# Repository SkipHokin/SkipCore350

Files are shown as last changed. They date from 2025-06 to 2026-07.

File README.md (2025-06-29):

# SkipCore350 Project Context & Vision

**Project Name**: SkipCore350  
**Type**: Open Source CoreXY 3D Printer  
**Build Volume**: 350mm x 350mm x 350mm  
**Lead**: Skip Hokin (aka "Skip")

---

## ✨ Vision Statement

To design and build a high-performance, low-cost, fully enclosed CoreXY 3D printer using open-source principles, V-slot extrusions, and widely available components. SkipCore350 aims to be:

- Builder-friendly and easily replicable
- Mechanically robust with smooth motion (MGN12 rails + GT2 9mm belts)
- Modular and maintainable
- Capable of printing engineering-grade filaments
- Designed for clean enclosure and cable management

The goal is to offer makers a DIY alternative to high-end machines, blending the precision of industrial designs with the accessibility of community-driven innovation.

---

## 📊 Project Overview

SkipCore350 is a fusion of SimpleCore-style motion with modern practices:

- CoreXY motion system for speed and accuracy
- Triple Z leadscrew driven by a single stepper via GT2 belt
- Full 2020/2040 V-slot aluminum frame
- MGN12H rails on all axes for rigidity and future upgradeability
- Compatibility with BTT Pad7 and SKR-based boards
- Designed around off-the-shelf parts and printable brackets

Future-proofed to support direct-drive or Bowden extruders, enclosure panels, toolheads, and more.

---

## 🏋️ Key Milestones

1. Frame assembly and CAD layout (Blender)
2. Release of printable STLs for motion and brackets
3. BOM creation and sourcing notes (Aliexpress, local)
4. Wiring + electronics integration
5. Functional build and print validation
6. Documentation, GitHub publishing, and community feedback

---

## 🚀 Intended Use

Perfect for:

- Functional prototyping
- Mechanical parts and jigs
- Enclosed prints (ABS, ASA, PC)
- Builders seeking a dependable, modifiable platform

Whether you’re a hobbyist, educator, or small-shop maker, SkipCore350 aims to be a reliable workhorse you can understand, build, and tweak as needed.

---

## 👥 Community & Attribution

SkipCore350 draws inspiration from:

- Voron / Trident mechanics
- SimpleCore structural layout
- Contributions and STLs from the open source 3DP ecosystem

All third-party parts used will be credited accordingly. Contributions welcome. Attribution is key to the spirit of this project.

**Attribution Format for STLs:**  
If reusing or modifying community-designed STLs:
- Original filename (and author if known)
- License used (e.g. CC BY, MIT)
- Modified filename (if applicable)
- Note in `CREDITS.md`

Example:
```
z_motor_mount_simplcore.stl - Original from SimpleCore by [Author] (CC BY 4.0)
z_motor_mount_skipmod.stl - Modified for SkipCore350
```

---

## 💪 Let’s Build Something Great

SkipCore350 is more than just a printer — it’s a collaborative process. A chance to explore design, motion, and fabrication from the ground up. With the right mix of smarts, patience, and 9mm belts, we'll build a machine that punches well above its budget.

---

**Repo**: [https://github.com/SkipHokin/SkipCore350](https://github.com/SkipHokin/SkipCore350)  
**License**: MIT

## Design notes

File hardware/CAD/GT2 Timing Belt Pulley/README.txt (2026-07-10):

Timing Belt Pulley - GT2 20 Teeth by MrAmericanMike on Thingiverse: https://www.thingiverse.com/thing:2503601

Summary:
4 Versions of a same pulley style.GT2 20 Teeth with 5mm inner hole diameterv01 have a circular holev02 have a flat side on themFiles names "Tolerances" have a 0,1 to 0,2 tolerance on the teeth and on the inner hole.Test what works better for you.Outer diameter is 16mm. Teeth area is 7mm in width. Total piece height is 15,8mmLet me know how it works for you guys. I may upload more variations if someone needs them ;)PS: Print in the best resolution possible and if you have a 0,3mm (or smaller) nozzle even better I guess.

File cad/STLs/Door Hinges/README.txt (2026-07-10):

Hinges 180° and 270° - 34 Sizes, All Purpose, Print-in-Place, Ready-to-Print by guppyk on Thingiverse: https://www.thingiverse.com/thing:4783423

Summary:
First, I really hope you like the design and find it useful. If you feel like tipping, rather than hitting the "Tip Designer" button, PLEASE donate to UKRAINE (or any other people in need). There is a cold winter ahead and these people will need any help they can get (and they will need it a lot more than I do)! THANKS!!  UPDATE 26Mar21. If 270° isn't enough for you, I have just uploaded a full set of 360° hinges. Happy printing!https://www.thingiverse.com/thing:4804593HingesA collection of 34 different all purpose, ready-to-print, print-in-place hinges from 30 x 20 mm (1.2 x 0.8") to 100 x 50 mm (3.9 x 2"). They are surprisingly strong and come in thirteen sizes and in two flavors, 180° and 270°. This means that they can either be opened to a maximum angle of 180° or 270°, depending on what you need them for (it may come handy when the hinge stops at 180° but sometimes you may need the full 270° - also see the image above). Actually I just needed a few hinges for a woodworking project and was just too lazy to adapt some existing design - ended up making a few more and thought it might be worth sharing. :-)PRINTING. This should be an extremely simple (and fast) print. You should not need any supports or plate adhesion. Print-in-place simply means that you only need to print a single piece (rather than 2 pieces and a rod) and that it does not require any assembling. Print in 0.1 mm (for me 0.2 with adaptive layers also works) resolution with 50%+ infill (on any moderately well calibrated printer).I print all mine using some cheap, strong, and easy to print Carbon Fiber PLA but any strong filament (that does no stringing) will do.They also look real good in Silk Silver or Gold, but may not be as strong.SIZES.These are the sizes currently included (size is width across both parts x height, all in 180° and 270° - they are all 4 mm thick, except for the x30 mm hinges, which are available in 3 and 4 mm):100 x 50 mm   (3.9 x 2")100 x 40 mm   (3.9 x 1.6")80 x 50 mm   (3.1 x 2")80 x 40 mm   (3.1 x 1.6")60 x 50 mm   (2.4 x 2")60 x 40 mm   (2.4 x 1.6")40 x 40 mm   (1.6 x 1.6")40 x 30 mm   (1.6 x 1.2") (in 3 and 4 mm)36 x 30 mm   (1.4 x 1.2") (in 3 and 4 mm)30 x 30 mm   (1.2 x 1.2") (in 3 and 4 mm)24 x 30 mm   (0.9 x 1.2") (in 3 and 4 mm)40 x 20 mm   (1.6 x 0.8")30 x 20 mm   (1.2 x 0.8")PS.: The 30 mm hinges (## x 30 mm) are available 3 AND 4 mm thick. The 3 mm hinges work well but are considerably more fragile, so if you are having issues with stability, try the same size in 4 mm.HOPE YOU LIKE THEM, AND IF YOU LIKE THEM, PLEASE LIKE THEM. THANKS!Happy printing!UPDATE 21Mar21. I have just added a full set of the 30 mm hinges in 4 mm thickness (previously only available 3 mm).UPDATE 12Mar21. Upon request I have just added another four XS hinges: 40 x 20 mm (1.6 x 0.8") and 30 x 20 mm (1.2 x 0.8") in 180 and 270°. These are really cute and work extremely well. Happy printing!.PS.: This post may contain affiliate links and I may I get commissions for purchases made through links. You can support me by simply ordering through these links (and it won't cost you any extra).

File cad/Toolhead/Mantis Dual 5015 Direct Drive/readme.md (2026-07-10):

Mantis Dual 5015 Toolhead by Long
============
    
**Note: updates are staged at [https://github.com/mandryd/VoronUsers/tree/master/printer_mods/Long/Mantis_Dual_5015](https://github.com/mandryd/VoronUsers/tree/master/printer_mods/Long/Mantis_Dual_5015).  Go there for most recent stuff.**

<table width=100%>
<TR>
<TD align="center"><B>Link</TD><TD align="center"><B>Description</TD></TR>
<TR><TD align="center"><a href="readme.md">Readme</A></TD><TD align="center">Mantis Description and Updates</TD></TR>
<TR><TD align="center"><a href="bom_acknowledgements.md">BOM and Acknowledgements</A></TD><TD align="center">BOM, links to other repositories, acknowledgements</TD></TR>
<TR><TD align="center"><a href="print_orientation.md">Print Orientation</A></TD><TD align="center">Printing the parts</TD></TR>
<TR><TD align="center"><a href="carriage_assembly.md">Carriage Assembly</A></TD><TD align="center">Building the MGN9, MGN12 Carriage, Hotend Mounts</TD></TR>
<TR><TD align="center"><a href="magprobe.md">Magprobe Assembly</A></TD><TD align="center">Assembly of Mag Probe</TD></TR>
<TR><TD align="center"><a href="firmware_slicer_settings.md">Firmware and Slicer Settings</A></TD><TD align="center">Firmware and Slicer Settings</TD></TR>
<TR><TD align="center"><a href="1.8_trident.md">Voron 1.8 and Trident</A></TD><TD align="center">Notes on Voron 1.8 and Trident</TD></TR>
<TR><TD align="center"><a href="final_assembly.md">Final Assembly</A></TD><TD align="center">Notes and Pictures of final assembly</TD></TR>
<TR><TD align="center"><a href="https://github.com/mandryd/MantisUsermods/tree/main/Usermods">Usermods</A></TD><TD align="center">Mods by Mantis Users (note: separate repository)</TD></TR>
<TR><TD align="center"><a href="https://github.com/mandryd/VoronUsers/tree/master/printer_mods/Long/Mantis_Dual_5015">Long's Mantis Repository</A></TD><TD align="center">Long's Repository for Mantis.  Updates and newest stuff will be found here</TD></TR>
</table>
  
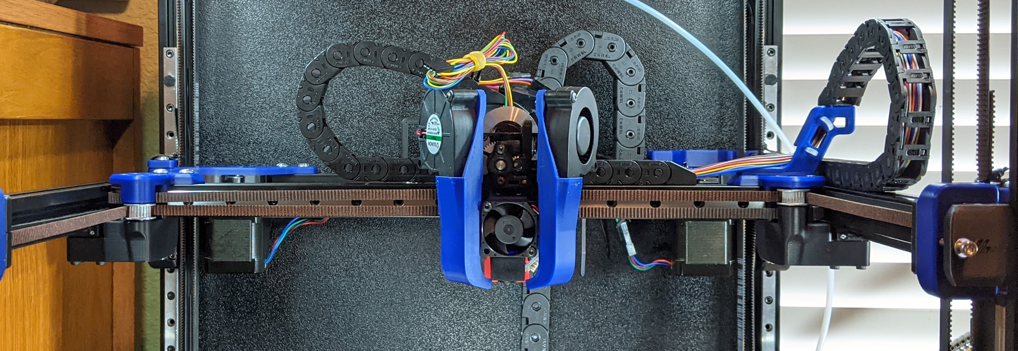
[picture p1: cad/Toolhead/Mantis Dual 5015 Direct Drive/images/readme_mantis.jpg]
    
  
<TABLE>
<TR><TD Colspan=3 align="Center"><B>CFDs</B></TD></TR>
<TR><TD colspan=3 align="center" width=100%>Mantis ducts are optimized for the hotend they are paired with.  <BR>Depending on the geometry of the heatblock/sock around the nozzle, it is easier or harder to cool the nozzle.  If the width of the hotend around the nozzle is narrow, the ducts can be opened up and a higher max part cooling flow can be achieved.  </TD></TR>
<TR>
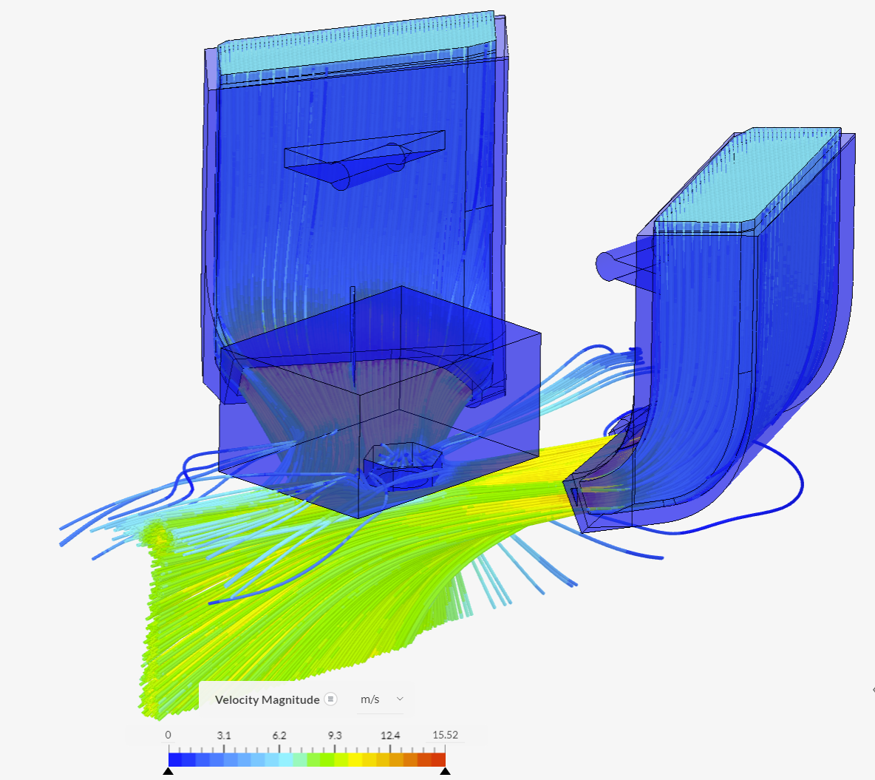
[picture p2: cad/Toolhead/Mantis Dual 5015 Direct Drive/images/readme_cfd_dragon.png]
    <TD width=33% align="center" valign="top"></TD>
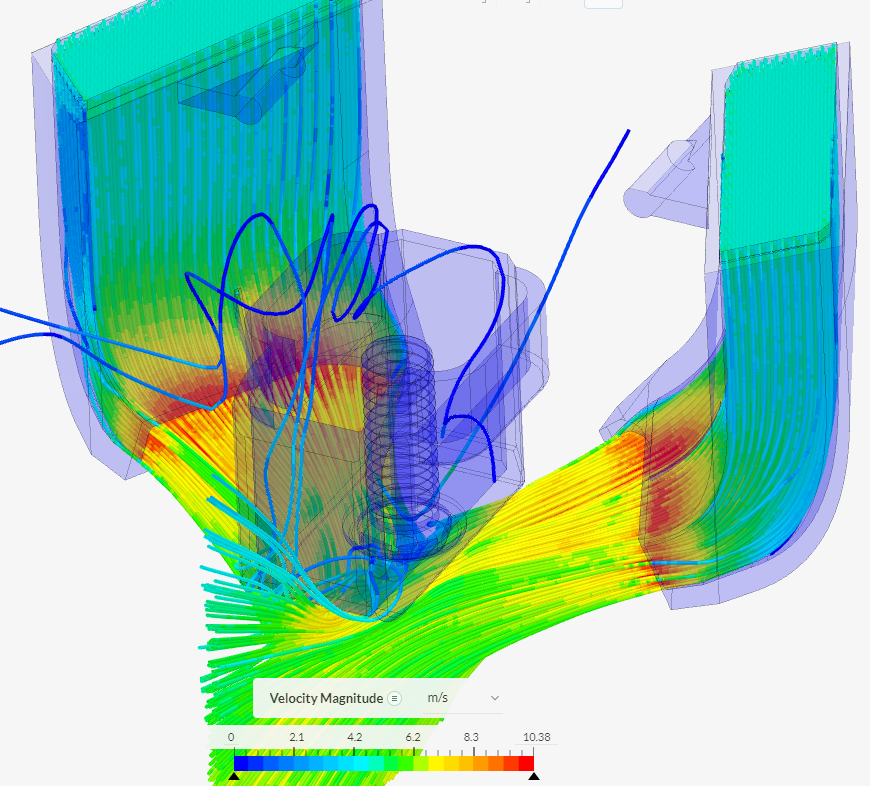
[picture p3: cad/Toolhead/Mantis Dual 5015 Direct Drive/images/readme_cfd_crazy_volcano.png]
    <TD width=33% align="center" valign="top"> </TD>
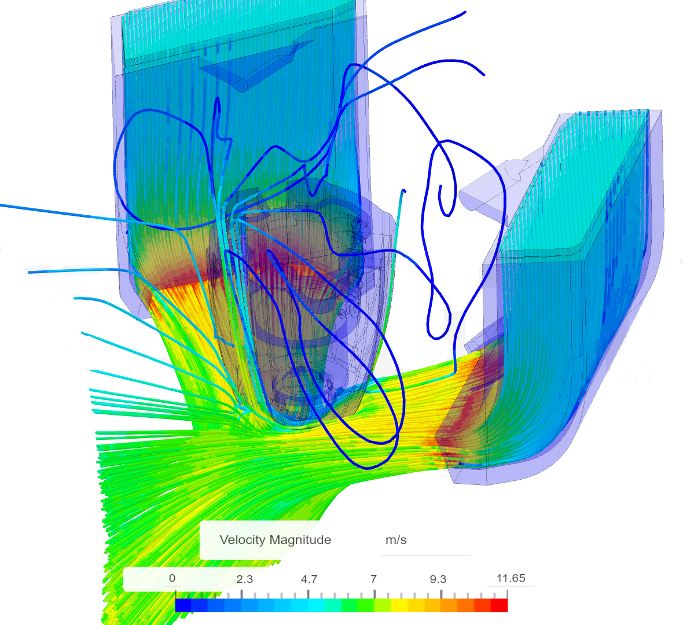
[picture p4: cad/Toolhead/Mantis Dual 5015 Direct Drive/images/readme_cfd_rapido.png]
    <TD width=33% align="center" valign="top"></TD>
</TR>
<TR>
    <TD width=33% align="center" valign="top"><B>Dragon</B><BR>Lower part cooling than rapido/crazy volcano ducts due to the wide nature of the v6 block.  Still way more than a single 5015 duct that has been split, and more cooling than most people will ever need.</TD>
    <TD width=33% align="center" valign="top"><B>Crazy Volcano Block/Dragon Heatsink</B><BR>This duct has highest amount of airflow due to the narrow shape of the heatblock.  This pairs well with the high melting capabilities of Crazy Volcano (~45-50 mm^3/s plastic). </TD>
    <TD width=33% align="center" valign="top"><B>Rapido HF</B><BR>This duct has slightly less air flow than the Crazy Volcano version, but more than dragon block.</TD>
</TR>
</TABLE>
  
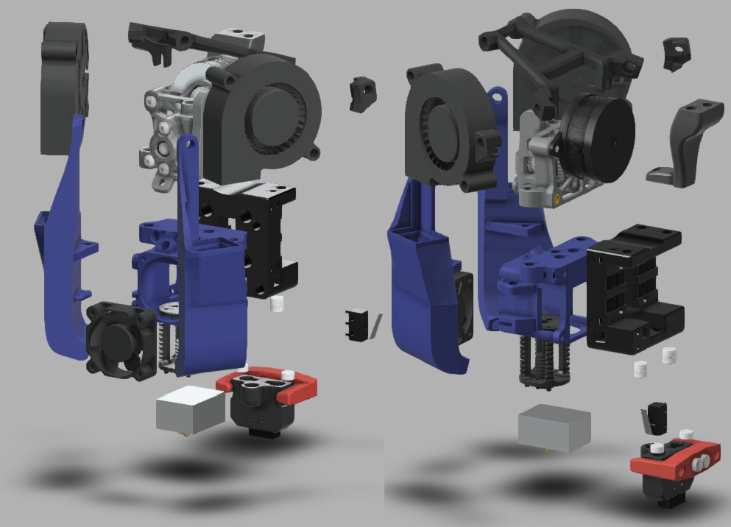
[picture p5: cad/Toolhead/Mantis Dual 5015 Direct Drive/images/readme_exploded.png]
   

**Features:**
- Single MGN9 or MGN12 X-Rail.  Just print out the corresponding carriage.
- Hotends
  - Dragon
  - Rapido HF/UHF
  - Mosquito (from usermod by WingZero)
  - Crazy Volcano with Dragon or Mosquito Heatsink
- Dual 5015
  - ***Minimum layer time can be much lower.***  I'm using 5 seconds conservatively on 0.2 layer height.
  - Left to Right airflow balance is no longer an issue
  - Single piece ducts without splitting and fewer bends = less duct losses.  Dual 5015 is probably at least 3x airflow compared to a single split 5015.
- Lighter
  - Mantis tool head weighs ~290g including the carriage
  - Spec AB is ~470g.  Spec AB with gailieo is ~375g.  Stealthburner beta is ~410g.
  - Using single MGN9 removes an additional ~140g from the Y axis on a 300.  
- Stiffer
  - Single piece carriage and hotend mounts stiff and light.
- Detachable Bed Probe (magprobe)
  - Decreases weight, allows shrinkage of the carriage, and movement of weight closer to the extrusion.
  - Direct probing of the bed surface.  Allows usage of any bed surface. 
- Weight moved closer to the rail for less lever.
  - Hotend is moved closer the rail +y, and upwards +z
  - Fans are rotated so the mass is further back.  
- Decreased length from extruder to hotend
  - Bowden from mini-sherpa to Dragon is only 19mm
- X-endstop relocated to carriage.  Easy to transition to umbilical if desired.
  - X-endstop must be relocated because the Mantis carriage is smaller and does not hang down far enough to trigger the endstop pod.
  - Y-endstop can still be from the spec endstop pod on the right xy-joint, however **I highly recommend relocating the y-endstop to the right a/b drive.**  
    - Normal 2.4 version - [https://github.com/hartk1213/MISC/tree/main/Voron%20Mods/Voron%202/2.4/Voron2.4_Y_Endstop_Relocation](https://github.com/hartk1213/MISC/tree/main/Voron%20Mods/Voron%202/2.4/Voron2.4_Y_Endstop_Relocation)
    - [Pin mod](https://github.com/hartk1213/MISC/tree/main/Voron%20Mods/Voron%202/2.4/Voron2.4_Pins_Mod) 2.4 version - [https://github.com/hartk1213/MISC/tree/main/Voron%20Mods/Voron%202/2.4/Voron2.4_Pins_Mod/STLs/Gantry/AB_Drive_Units](https://github.com/hartk1213/MISC/tree/main/Voron%20Mods/Voron%202/2.4/Voron2.4_Pins_Mod/STLs/Gantry/AB_Drive_Units)
  - Ditching the cable chain would save around 150g on the x-axis for a Voron 300.  
- Area around heat block is very open.  Ducts give wide berth to block to decrease melting issues.
    
 **Cons:**
- With spec front idlers, you will lose space at the front corners of the bed ~10mm in X at each idler.  
- There are now alternative idlers that allow use of Mantis with minimal to no loss of build area
  - Rama - https://github.com/Ramalama2/Voron-2-Mods/tree/main/Front_Idlers 
  - Phalanx - https://github.com/selliott79/Other-V2-Idlers 
- Some parts like the ducts and hotend mount are a bit tricky to print.
-  Thumb screw for the mini-sherpa will not fit.  Use a buttonhead to save space.
  - Standard 12mm spring should work with the button head.  
  - I used 6mm diameter x 0.9mm coil diameter x 10mm length springs for extra clearance, but this is unnecessary.
  - (Replaces stock 6mm x 1mm x 12mm spring) 

Changelog
-----------------
06-08-2022
- Updated CADs to include the fan braces.
  - Dragon CAD now includes both versions of the ducts (normal and higher flow variant) and also the hotend mount that braces the sherpa mini.
  - There's been a bunch of additions on the usermods, so go check it out!
        
06-03-2022
- Added links and documentation (under <a href="carriage_assembly.md">Carriage Assembly</A>) regarding Hotend_Mount_Dragon_v1.040_sherpa_brace.stl and the <a href="https://github.com/Annex-Engineering/Annex-Engineering_User_Mods/tree/main/Extruders/Sherpa_Mini/Extruder_Mods/Long-housing_front_angled_front_brace">modified Sherpa Mini housing_front</A>
        
05-29-2022
- Added Hotend_Mount_Dragon_v1.040_sherpa_brace.stl.
  - This is a modified hotend mount which mates with a modified housing_front that triangulates the sherpa mini mounting.  
  - Since the modified housing_front is an annex part, it will be hosted on their usermods under sherpa mini (I have a PR in there now).
        
05-05-2022
- Added duct_dragon_v1.043e.  These are a newer version of the ducts for Dragon.  These have slightly less build plate clearance but bigger duct outlets, so higher cooling potential.  I've been running them for a while now and haven't crashed the ducts into a print yet.  
        
04-30-2022
- Uploaded [Duct Braces](STLs/Duct_Brace) that support the fans at the rear.  These bolt from the upper duct arms to the rear of the 5015s to the motor mounts of the sherpa mini.  This greatly improves the resonance graphs in X (attenuates the 125hz peak on the X axis).  
        
3-31-2022
- <S>I received a report of heatcreep using a winsinn 3010 with Rapido.  Just something to be aware of if you're planning to use that combo.  I personally haven't had issues with rapido, but I'm using a sunon 3010v1.</S>  (apparently the jamming was caused by an overheating extruder motor, not heat creep) 
        
1-27-2022
- TheWarolf has added LGX Lite compatibility in his repository of Mantis mods.
  - https://github.com/TheWarolf/Voron-Personal-Mods/tree/main/V2/Long_Mantis_Toolhead
- Usermods has been broken out of the main repository.  Everything is still there, but it is now located [here](https://github.com/mandryd/MantisUsermods/tree/main/Usermods)
        
1-24-2022
- added Duct_Brace_v1.stl.  This connects the ducts together via the two upper 5015 mount holes reducing the lateral motion of the 5015 fans and resulting in an improvement in the ADXL graph (helps mitigate a resonance at ~110hz).  I didn't have issues with ringing before this brace, but it does make the graph look nicer.  
        
1-17-2022
- Uploaded slightly updated ducts (duct_dragon_v1.041, duct_rapido_HF_v0.03b, duct_rapido_UHF_v0.03b, duct_dragon_crazy_volcano_v1.0).  This will be an easy swap for your existing ducts.
  - These ducts increase the diameter of the lower "peg" on the ducts.  This tightens the lower joint of the hotend mount to duct and should help with the ducts pivoting over the joint of the upper duct to hotend mount.
  - Updated the CAD files to match these updates.
        
1-10-2022
- Added Mods by [Usermods by TheWarolf](https://github.com/TheWarolf/Voron-Personal-Mods/tree/main/V2/Long_Mantis_Toolhead)
  - ERCF Hotend mount which incorporates a filament sensor
  - Modified MGN12 carriage which fits the sailfin extruder
  - Umbilical mount which mates with the popular cable gland people have been using for umbilicals.
        
12-20-2021
- Added CAD files for Mantis with Crazy Volcano and Rapido (note that rapido is still in development)
    
12-19-2021
- Hotend_Mount_Dragon_v1.040
  - noticed a slight interference between the hotend mount and the ducts.  Adjusted so no more interference.  This should only affect you if you're using crazy volcano.
- Rapdio UHF ducts
  - Added ducts that are 8.5mm longer than the Rapido HF ducts to support the UHF.
  - **Don't forget to also make the longer Rapido UHF magprobe**
    
12-18-2021
- Updated readme so it is now in markdown.  No more readme.pdf!
- Added ducts for Rapido HF v0.02 under 2.4.  
  - You will also need to the rapido hotend mount.  **When installing the sock, the Phaetus logo should face directly forward.** The wires for the hotend should come out the right.
  - As with all my ducts, these have been optimized for the particular hotend that is being used.  As I have not yet received my Rapido, I can't confirm that these ducts/hotend mount works correctly yet.
- Rearranged files somewhat to accomodate a growing number of ducts

12-07-2021
- Rapido Hotend Compatibility
    -  The Rapido hotend is the same length as the Crazy Volcano/Dragon and should work using the Crazy Volcano ducts and magprobe.  I will be confirming part cooling CFDs and will make adjustments to make it fully compatible soon.  I have a Rapido on order so will be able to personally test this as well.  
    - The Rapido sock is very chonky.  For optimum part cooling, I will probably need to rotate the hotend slightly (slightly modified hotend mount part).  When mounted into the existing dragon heatsink holes, the triangular sock of the Rapido isn't square to the front of the carriage at the bottom (will need to confirm this when I receive mine).  
    - I'm considering making two sets of ducts for Rapido
      - One where the airflow clears the Rapido Sock
      - Second set of ducts where the sock is trimmed slightly at the bottom to allow for slightly bigger duct outlets and slightly better part cooling.  Trimming the sock will allow a better angle of attack for part cooling to the nozzle.
      - Note that both of these part cooling ducts will outperform the standard Mantis ducts because the Rapido is narrower at the bottom than the Dragon.  

11-29-2021
- Added WingZero's [Mosquito Hotend Mount](https://github.com/mandryd/MantisUsermods/tree/main/Usermods/Wingzero) for Mantis using 2510 hotend fan.  Thanks for a lot of work and testing for this mod!
- Added my mod of WingZero's mosquito mount which uses a 3010 fan instead of the 2510.  This mount is still alpha and needs more testing for confirmation.
- Crazy Volcano is now compatible
  - Added beta part cooling ducts and mag probe that should work with dragon/[crazy volcano block](https://www.aliexpress.com/item/1005003506351141.html).  
  - Note, to use the crazy volcano with dragon heatsink, the only different files you will need are the crazy volcano ducts (located in the 2.4 folder), and the longer magprobe (in the magprobe directory).
  - The part cooling ducts require cutting the rear fan ears off of your 5015s.  If you dont want to cut the ears off your ducts, I will post higher mounting 5015 ducts soon, or message me directly.  

11-3-2021
- Updated MGN12 carriage (Carriage_MGN12_v1.040.stl).  Updated the wire path from the magnets and x-endstop switch so they don't go through the hotend exhaust path.  Also improved the hotend exhaust path so it should flow a bit better.
- Added a usermods folder.  Adding the mods in and crediting the creator in the filename was getting unwieldy, so Mantis now has a usermods folder.
- Added a mount for Hartk PCB Board by Charles

10-11-2021
- Added Mantis Toolhead PCB by Henrikssn.  
- Added Mgn9 Klicky Carriage by Henrikssn.  This is a modded single mgn9 carriage that works with Josar's Klicky magprobe
- Added Flat Flexible Cable (FFC) mod by Be Water.  Allows use of the [FFC Kit by Schmidt Proto](https://www.schmidtproto.com/product-page/voron-2-4-ffc-mod-kit) with Mantis

9-23-2021
- Added carriage for Mantis that uses a single MGN9 linear rail.  I am currently using this with a RobotDigg 440 SUS rail and it's working well.  Thanks to Bob Arctor and Henrikssn for their bravery in testing the early versions of this.
- Updated Readme_v1.07.pdf.  Added info for the MGN9 Carriage, fixed some wording, added link to Rama's option for narrow front idlers.
- Added ducts for Voron 2.4 that are 1.5mm shorter.  Decreases the clearance from 3.5 to 2mm.  No real advantage except if you like the shorter duct arm appearance.
  
7-18-2021
- Now compatible with Voron 1.8!
- updated readme
- changed directory structure for clarity
- magprobe dock arms v1.5 - new version of dock arms (for bed and gantry mount) which are tighter and longer (thanks to ShinyPants for lots of testing with these)
- carriage_v1.037 - minor revision adds a hole on the left side for ADXL mounting (thanks koonweee)
- chain_anchor_v3.2 - moved the front ziptie location higher.  added a rear ziptie location. (thanks koonweee)
- mantis_v1.037a.step updated - includes the above changes

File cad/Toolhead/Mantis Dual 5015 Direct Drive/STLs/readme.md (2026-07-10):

What to Print
============
****note that Voron 1.8 is only compatible with Dragon hotend at the moment.**  If you need something else just let me know and I'll work with you.

<table width=100% border=1> 
<TR>
<TD align="center" bgcolor="black"><font color="white"><B>Hotend</TD>
<TD align="center" bgcolor="black"><B><font color="white">Parts</TD>
<TD align="center" width=50% bgcolor="black"><B><font color="white">Notes</TD>
</TR>
<TR>
<TD align="center">Dragon<BR>(2.4 and Trident)</TD>
<TD align="center">Hotend_Mount_Dragon_v1.040.stl
<BR><B>-or-</B>
<BR>Hotend_Mount_Dragon_v1.040_sherpa_brace.stl
<BR>
<BR>duct_dragon_v1.041_left.stl
<BR>duct_dragon_v1.041_right.stl
<BR><B>-or-</B>
<BR>duct_dragon_v1.043e_left.stl
<BR>duct_dragon_v1.043e_right.stl
<BR>
<BR>Magprobe_v0.31_Dragon.stl
</TD>
<TD>
Hotend_Mount_Dragon_v1.040_sherpa_brace.stl allows usage of <a href="https://github.com/Annex-Engineering/Annex-Engineering_User_Mods/tree/main/Extruders/Sherpa_Mini/Extruder_Mods/Long-housing_front_angled_front_brace">modified sherpa mini housing_front</A>, which triangulates the sherpa mini mounting and adds extra stability.  
<BR>
<BR>Duct v1.041 is the standard duct.  It has good build plate clearance and plenty of airflow.<BR><BR>Duct v1.043e has less slightly less build plate clearance, but has larger duct outlets and higher cooling potential.  
</TD>
</TR>
<TR>
<TD align="center">Dragon<BR>(Voron 1.8)</TD>
<TD align="center">Hotend_Mount_Dragon_v1.040.stl
<BR><B>-or-</B>
<BR>Hotend_Mount_Dragon_v1.040_sherpa_brace.stl
<BR>
<BR>Duct_v1.037_Left_+2mm.stl
<BR>Duct_v1.037_Right_+2mm.stl
<BR>Magprobe_v0.31_Dragon.stl
</TD>
<TD>Note, because Voron 1.8 has an inverted gantry, the rear ear of the 5015 fans must be cut off.  Some people have reported being able to use the standard v2.4 ducts with a very very close clearance.  <BR><BR><I>The Full duct brace will not work with the +2mm versions.  </I>
<BR><BR>Hotend_Mount_Dragon_v1.040_sherpa_brace.stl allows usage of <a href="https://github.com/Annex-Engineering/Annex-Engineering_User_Mods/tree/main/Extruders/Sherpa_Mini/Extruder_Mods/Long-housing_front_angled_front_brace">modified sherpa mini housing_front</A>, which triangulates the sherpa mini mounting and adds extra stability.  
</TD>
</TR>
<TR>
<TD align="center">Mosquito</TD>
<TD align="center">hotend_mount_mosquito_30mm_fan_v0.42
<BR>
<BR>duct_dragon_v1.041_left.stl
<BR>duct_dragon_v1.041_right.stl
<BR><B>-or-</B>
<BR>duct_dragon_v1.043e_left.stl
<BR>duct_dragon_v1.043e_right.stl
<BR>
<BR>Magprobe_v0.31_Dragon.stl
</TD>
<TD>
The hotend mount is located in <a href="https://github.com/mandryd/MantisUsermods/tree/main/Usermods/Wingzero">usermods</A>
<BR>Thanks to Wingzero for making Mosquito Compatible!
<BR><BR>Duct v1.041 is the standard duct.  It has good build plate clearance and plenty of airflow.<BR><BR>Duct v1.043e has less slightly less build plate clearance, but has larger duct outlets and higher cooling potential.  
</TD>
</TR>
<TR>
<TD align="center">Crazy Volcano with Dragon Heatsink</TD>
<TD align="center">
Hotend_Mount_Dragon_v1.040.stl
<BR><B>-or-</B>
<BR>Hotend_Mount_Dragon_v1.040_sherpa_brace.stl
<BR>
<BR>duct_dragon_crazy_volcano_v1.0_left.stl
<BR>duct_dragon_crazy_volcano_v1.0_right.stl
<BR>Magprobe_v0.31_RapidoHF_and_CrazyVolcano.stl
</TD>
<TD>Hotend_Mount_Dragon_v1.040_sherpa_brace.stl allows usage of <a href="https://github.com/Annex-Engineering/Annex-Engineering_User_Mods/tree/main/Extruders/Sherpa_Mini/Extruder_Mods/Long-housing_front_angled_front_brace">modified sherpa mini housing_front</A>, which triangulates the sherpa mini mounting and adds extra stability.  
<BR></TD>
</TR>
<TR>
<TD align="center">Rapido HF</TD>
<TD align="center">
Hotend_Mount_Rapido_v.03.stl
<BR>duct_rapido_HF_v0.03b_left.stl
<BR>duct_rapido_HF_v0.03b_right.stl
<BR>Magprobe_v0.31_RapidoHF_and_CrazyVolcano.stl
</TD>
<TD><B>Print the hotend mount (Hotend_Mount_Rapido_v.03.stl or Hotend_Mount_Rapido_v.03_Rotated120Degrees.stl) that allows you to mount the Rapido hotend so that the wires come out right/forward and the logo of the sock faces directly forward</B>. <BR>Because the Rapido uses FOUR screws on the top of the heatsink, and THREE screws to mount the heater to the heatsink, the orientation of the hotend mount versus the heater wire can vary.  The Part cooling ducts for Rapido have been optimized so that the Phaetus logo on the sock should point directly forward (yes the sock is asymmetrical).  </TD>
</TR>
<TR>
<TD align="center">Rapido UHF</TD>
<TD align="center">
Hotend_Mount_Rapido_v.03.stl
<BR>duct_rapido_UHF_v0.03b_left.stl
<BR>duct_rapido_UHF_v0.03b_right.stl
<BR>Magprobe_v0.31_RapidoUHF.stl
</TD>
 <TD>See the RapidoHF notes on which hotend mount to print.<BR>Don't forget you will need to switch between magprobes if you switch between UHF and HF variant of the Rapido.</TD>
</TR>
</Table>

The Rest
-----------------
 - Carriage
   - Carriage_MGN12_v1.040.stl
   - Carriage_MGN9_v1.0.stl
 - Cable/Umbilical Chain
   - Cable Chain Mounts
     - IGUS - Chain_Anchor_v3.1_IGUS.stl
     - China - Chain_Anchor_v3.2.stl
   - Umbilical Mount - Umbilical_Mount_v2.stl
   - Also see the usermods for other potential options.
 - Duct braces can be used to improve stability of the 5015 mounting arms.  This will help with resonance compensation.  See the [Duct Brace Folder](Duct_Brace/)
 - Gantry or bed extrusion mag probe dock.
   - Gantry
     - Magprobe_Gantry_Extrusion_Mount_by_JosAr_v1.stl
     - Magprobe_Gantry_Dock_Mount_by_JosAr_v1.stl
     - Dock arms (I recommend the single magnet unless you have issues with your probe falling out during prints)
       - Magprobe_Gantry_Dock_Arm_v1.5_Single_magnet.stl
       - Magprobe_Gantry_Dock_Arm_v1.5_double_magnet.stl
   - Bed Extrusion
     - Magprobe_Dock_Arms_v1.5.stl
     - Magprobe_Dock_Mount_v1.0.stl

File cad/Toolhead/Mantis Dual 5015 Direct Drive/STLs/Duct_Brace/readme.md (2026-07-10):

Duct Braces
============

<TABLE width=100%>
<TR>
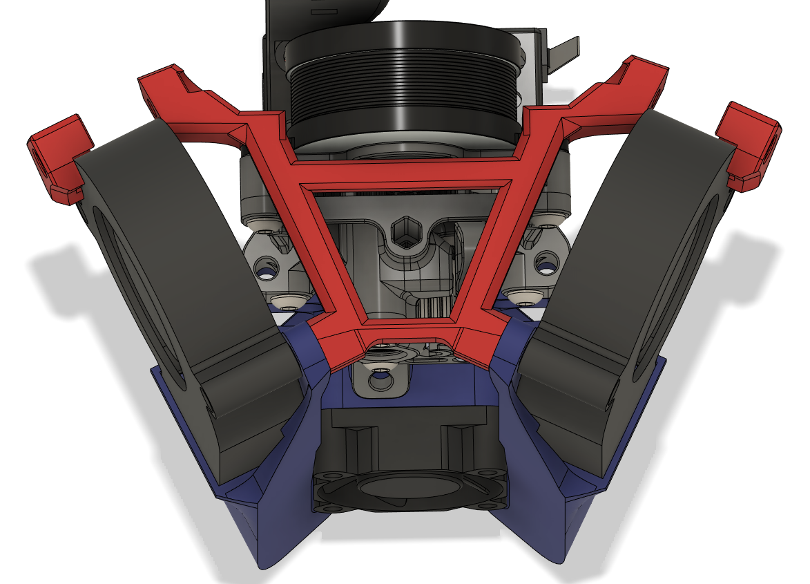
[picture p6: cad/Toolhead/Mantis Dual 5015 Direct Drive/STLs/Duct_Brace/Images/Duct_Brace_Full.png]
<TD width=50% align="Center" valign="TOP"><BR>Full Duct Brace</TD>
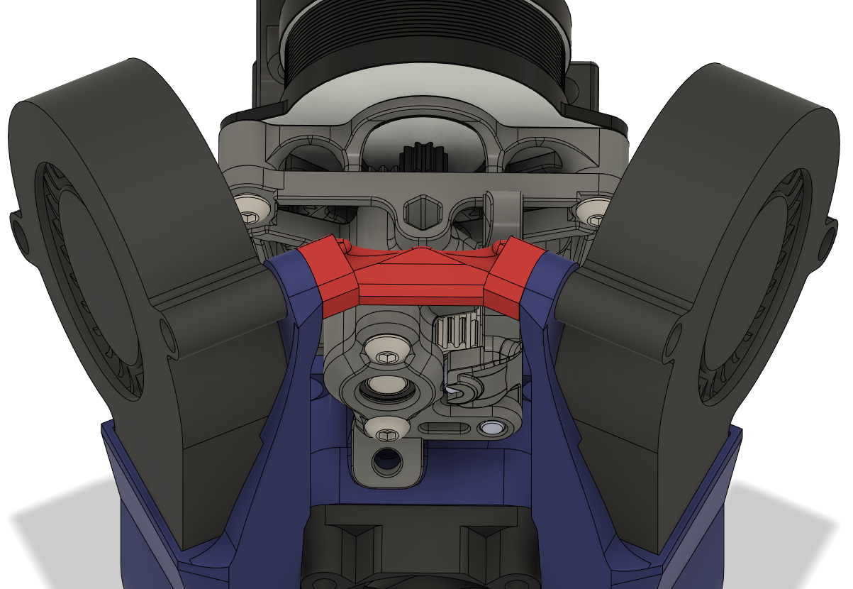
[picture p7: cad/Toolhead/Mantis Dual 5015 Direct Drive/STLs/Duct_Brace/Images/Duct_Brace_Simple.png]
<TD width=50% align="Center" valign="TOP">Simple Duct Brace</TD>
</TR>
<TR>
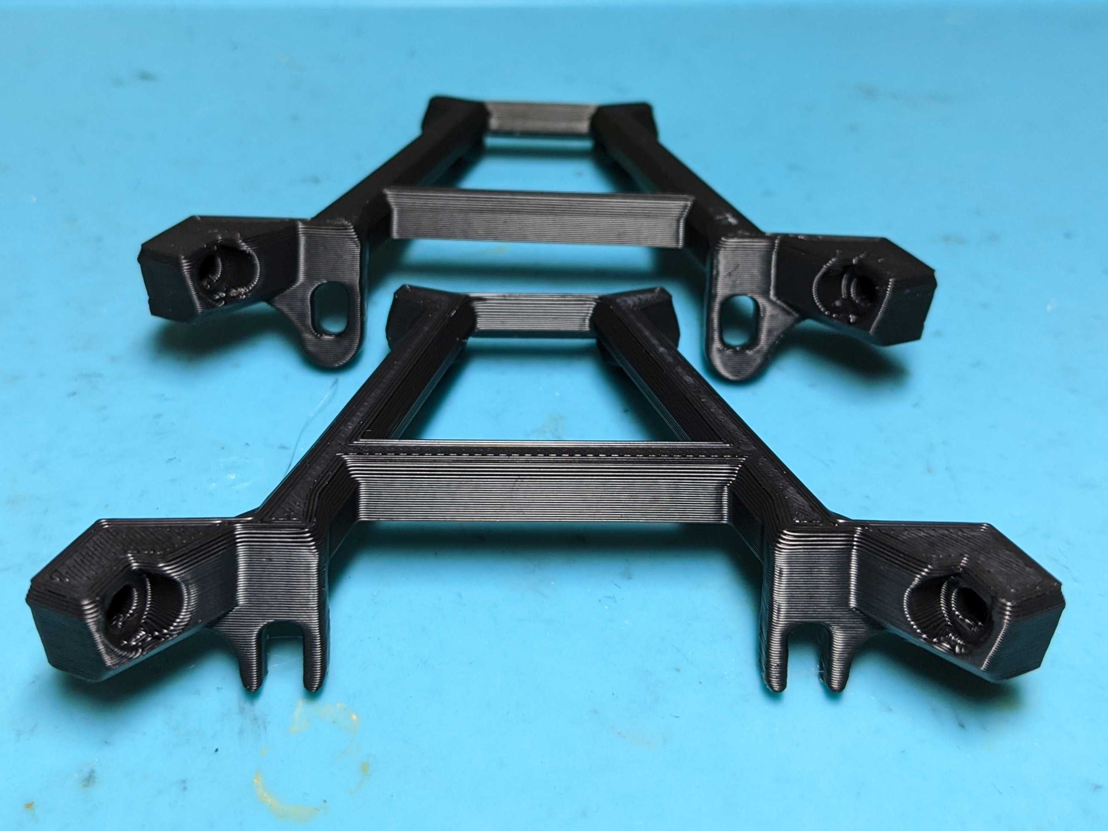
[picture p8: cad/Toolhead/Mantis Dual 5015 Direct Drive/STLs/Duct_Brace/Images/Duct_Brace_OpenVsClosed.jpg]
<TD width=50% align="Center" valign="TOP"><BR>Closed Mount (top) vs Open Mount (bottom) versions</TD>
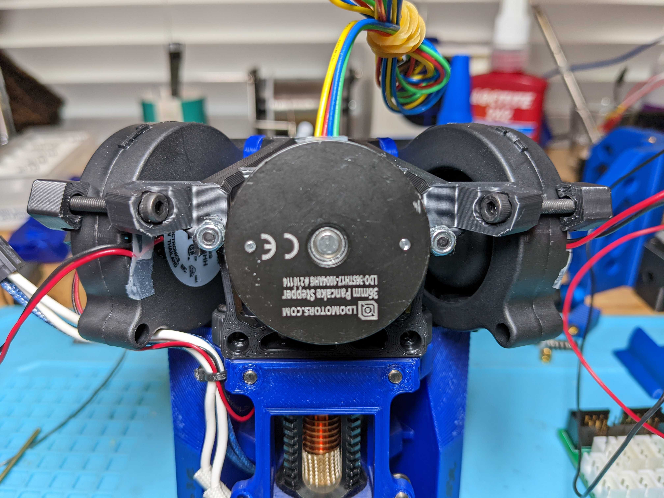
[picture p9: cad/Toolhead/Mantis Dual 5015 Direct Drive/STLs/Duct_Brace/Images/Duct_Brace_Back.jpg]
<TD width=50% align="Center" valign="TOP"><BR>Locknut to secure brace to motor.  <BR>Replace Sherpa mini to motor mount bolts with m3x20mm</TD>
</TR>
<TR><TD width=100% colspan=2 align="CENTER"></TD></TR>
</TABLE>

- **Purpose**
  - The Mantis 5015 mount is unstable due it being a single mounting point.  The rear and top part of the 5015s are susceptible to vibration on the x-axis resonance tests.  This results in a second 125hz peak on the X axis resonance graphs.
  - This is a rigid solution that makes the fan mounting much more stable and greatly decreases the 125hz peak.
- **Simple Brace Notes**
  - This is a quick and easy brace.  It decreases the x-axis resonance slightly and is very simple to install.  I highly recommend the full brace over the simple brace.
  - m3x25mm bolts through the upper duct arm mount and straight into the plastic of the duct brace.
- **Full Brace Notes**
  - *Just FYI, these are new parts, so I'm still polishing/adjusting things.*
  - There are two versions of the full brace parts.  
    - The open motor mount version is easier to mount but may be a weaker mounting surface, time will tell.  I bet it'll be ok.
    - The closed motor mount version is stronger, but requires you to unscrew the m3x20s during mounting of the duct.  It's not a big deal, but the option is there.  
  - I used a lock nut to clamp the duct brace to the sherpa mini motor.  This is annoying because there isn't enough space to fit a hex socket on the nut.  I'm looking into alternative ways to clamp the brace to the sherpa.
  - Yes, the rear 5015 clamp currently bolts from inside out.  The 4.5mm thick plastic + heatset clamps well and doesn't lean too much.  I'm looking into ways to have this clamp with the bolt head to the outside, but it works ok for now.  
    - The fans actually feel pretty rigid even without the clamps.  With more testing, the rear clamps may not be needed.  
  - Note: The clamps for **dragon** have slots to allow for the fan wires to pass though and thus need to be on the correct side.  
    - The clamps for rapido/crazy volcano do not require these slots, so left/right on the clamps shouldn't matter.    
- **Acknowledgements**
  - Thanks to Woenn for the idea for the simple duct brace.  He's the one that got me started on the bracing.
  - Thanks to Netweaver for the idea for the A-Frame connecting the sherpa mini motor to the front duct arms.  I took his idea and added the rear 5015 support/clamps.  He was relentless in testing and helping figure out where the extra vibration was coming from.

Changelog
============
- 05-02-2022
  - v1.2 full braces.  Added Slots to the rear fan clamping (where the bolthead goes at the rear of the horizontal brace).  Some 5015s are larger than others, so this will allow for some size differences.

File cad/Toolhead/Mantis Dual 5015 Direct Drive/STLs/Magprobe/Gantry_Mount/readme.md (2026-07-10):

Gantry Mounted Mag Probe
============
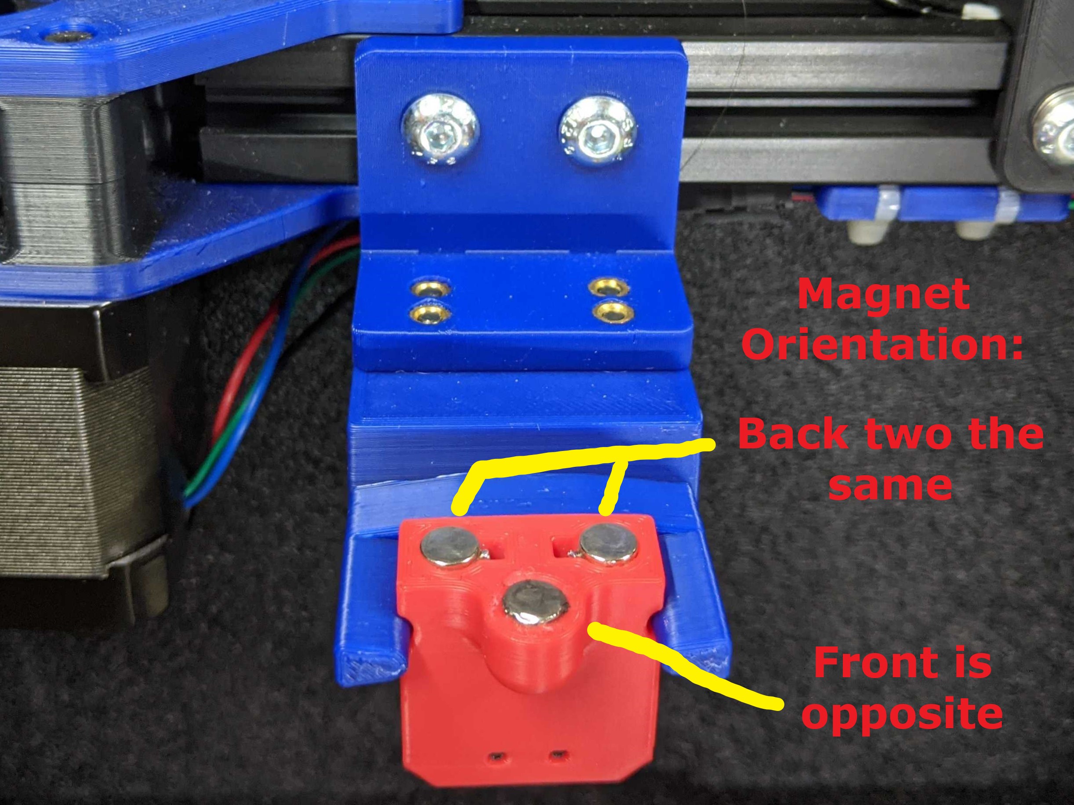
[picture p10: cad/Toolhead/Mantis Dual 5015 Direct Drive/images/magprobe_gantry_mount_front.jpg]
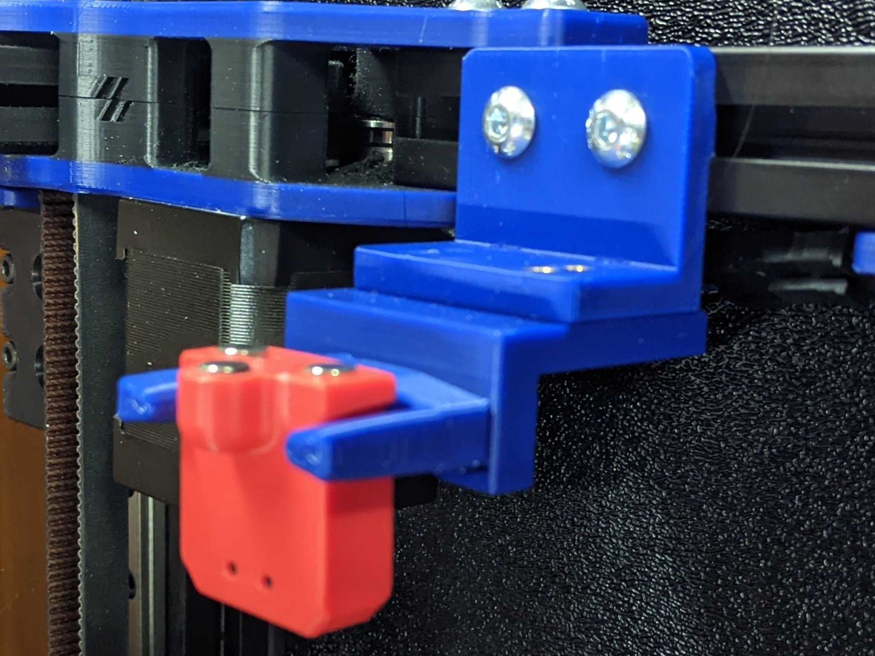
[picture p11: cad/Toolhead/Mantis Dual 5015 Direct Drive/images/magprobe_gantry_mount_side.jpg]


- Print the dock mount, extrusion mount, and either of the dock arms.
  - Depending on your machine and the m2 screws you used on your mag probe, you may need the double magnet version of the dock arms.  I am using the single magnet version and I havent had the magprobe fall out during printing yet.  However some poeple have needed the double version.  I would say start with the single magnet version then swap to the double if necessary.
- Adjusting your dock mount
  - Height
    - This is straightforward. Adjust the height so the probe lines up with the arms.
  - Forward Reach 
    - I have my dock adjusted so that the magprobe, when docked, is actually a few mm further back (+y) than where the magnets of the carriage can reach.  
      - For example.  If the carriage magnets are at y305.  Then the mag probe magnets, when in the dock, can be at around y308 (out of the actual moveable range of the printer)
    - When picking up the probe, the mag probe will snap forward to the carriage magnets.  
    - When dropping off the probe, as the toolhead moves to the side, the mag probe will snap back to the dock.  
    - This allows you to have the magprobe just a few more mm out of your printing area.

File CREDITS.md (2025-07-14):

# SkipCore350 – Attribution & Credits

This document lists the open-source components, models, and inspirations used in the SkipCore350 project, with proper attribution to original creators as per their license requirements.

---

## 🔧 Reused or Referenced STLs

| STL Filename | Source Project | Original Author | License | Notes |
|---|---|---|---|---|
| z_motor_mount_simplcore.stl  | SimpleCore | [Author Name] | CC BY 4.0 | Original mount used as reference |
| z_motor_mount_skipmod.stl | SkipCore350 | Skip | Derived Work  | Modified version for compatibility |
| bed_mount_railclip.stl | SimpleCore | [Author Name] | CC BY-SA 3.0  | Rail clip used on Z axis for bed mount |
| ... | ... | ... | ... | ... |

> **Note:** Original files are kept in `/STL/original/`, modified files in `/STL/modified/`.

---

## 💡 Project Inspiration

- **SimpleCore** by Timawa3D (Printables/GitHub) — frame and motion base
- **Voron Trident** — CoreXY belt layout and frame scaling ideas
- **BTT Pad7 / SKR Boards** — hardware compatibility and firmware inspiration

---

## 📜 License Compatibility

All reused STLs and designs follow open-source licenses that allow modification and redistribution with proper attribution. Please retain credit if you further modify and share these files.

If you're an original author and would like updates or corrections made here, please raise an issue or pull request on the GitHub repo.

---

Thank you to the open-source 3D printing community 🙏

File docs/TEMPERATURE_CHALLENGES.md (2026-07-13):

# SkipCore350 Temperature Challenges

This document captures the temperature-related problems, assumptions, fixes, and tests for SkipCore350.

Use this as a running record rather than a polished final answer. Add dates, screenshots, Klipper log snippets, photos, and final settings as they are confirmed.

---

## Current known context

- Controller: BTT Manta M8P v2.0 with onboard CB1.
- Firmware: Klipper.
- Bed heater: 230 VAC silicone heater, around 500 W.
- Bed control: SSR on bed output path.
- Bed sensor: THB / bed thermistor input.
- Hotend currently used during commissioning: E3D Revo Ceramic 24 V 60 W.
- Planned / alternate hotend: Rapido 2 UHF PT1000.
- Part cooling: dual 5010 fans; earlier testing suggested fan percentage must be kept conservative with the Revo Ceramic.
- Bed target used during early PLA/PLA+ tests: around 60 °C.

---

## Main risk areas

### 1. Bed heater and SSR safety

The bed is mains-powered, so this is not just a tuning issue. Treat the bed circuit as a safety-critical assembly.

Checklist:

- [ ] SSR is rated appropriately for the AC bed load.
- [ ] SSR heat sinking is adequate.
- [ ] Earth bonding is checked.
- [ ] Cable strain relief is fitted.
- [ ] Bed thermal fuse fitted and tested/inspected.
- [ ] Bed thermistor is firmly attached and cannot lift away from the plate.
- [ ] Bed temperature rises smoothly during a controlled test.
- [ ] Bed temperature falls when switched off.
- [ ] No unexpected heating occurs on firmware restart.

Notes:

```text
Date:
Observation:
Action:
Result:
```

---

### 2. Hotend temperature rise faults

Record any Klipper heater errors here. Useful items to capture:

- Exact error text.
- Target temperature.
- Starting temperature.
- Fan state.
- Silicone sock fitted or not.
- Ambient/enclosure temperature.
- Hotend type.
- Heater cartridge wattage.
- Thermistor/sensor type in config.
- PID values at the time.

Log template:

```text
Date:
Hotend:
Nozzle:
Material:
Target temperature:
Fan state:
Error message:
Relevant config:
Likely cause:
Fix attempted:
Result:
```

---

### 3. Revo Ceramic cooling sensitivity

Early commissioning notes indicate the E3D Revo Ceramic may be sensitive to excessive part cooling, especially with dual 5010 fans. Keep part cooling conservative until temperature stability is proven.

Initial conservative rules:

- PLA/PLA+: start part cooling low, around 25–35%.
- Do not run dual 5010 fans at full power during hotend temperature validation.
- Watch for temperature drop during bridges, overhang tests, and Benchy-style cooling changes.
- Tune fan limits before chasing speed.

Test log:

| Date | Material | Nozzle temp | Fan % | Result | Notes |
|---|---:|---:|---:|---|---|
| | | | | | |

---

### 4. PID tuning records

## Hotend PID

```text
Date:
Hotend:
Nozzle:
Target:
Fan state:
PID result:
Saved to config: yes/no
Notes:
```

## Bed PID

```text
Date:
Bed plate:
Target:
Enclosure open/closed:
PID result:
Saved to config: yes/no
Notes:
```

---

## Safe temperature test order

1. Verify room-temperature readings.
2. Heat hotend to 50 °C, then switch off.
3. Heat bed to 40 °C, then switch off.
4. Heat hotend to normal PLA temperature.
5. PID tune hotend.
6. Heat bed to 60 °C.
7. PID tune bed.
8. Run fan disturbance test on hotend.
9. Only then move into print tuning.

---

## Fan disturbance test

Goal: confirm the hotend can hold temperature while part cooling turns on.

Suggested procedure:

```gcode
M109 S220
M106 S64   ; about 25%
; watch hotend temperature
M106 S96   ; about 38%
; watch hotend temperature
M106 S128  ; about 50%, only if previous test is stable
M107
```

Pass condition:

- Hotend recovers without Klipper heater fault.
- No rapid uncontrolled drop.
- No oscillation large enough to affect printing.

Result:

```text
Date:
Fan percentage limit chosen:
Reason:
```

---

## Open questions

- [ ] Confirm final hotend: Revo Ceramic vs Rapido 2 UHF.
- [ ] Confirm final hotend temperature sensor type.
- [ ] Confirm final part cooling max percentage.
- [ ] Confirm bed heater SSR temperature during long heat soak.
- [ ] Confirm enclosure temperature during PETG/ABS/ASA tests.

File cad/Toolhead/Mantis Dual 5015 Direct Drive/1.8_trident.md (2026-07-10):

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

Voron Trident
============
**Notes for building on a Voron Trident**
- Trident is compatible with Mantis using the files for 2.4.  
  - Thanks to WingZero for testing this.

Voron 1.8 
============
**Notes for building on a Voron 1.8 (NOT trident)**
- You will need to cut the rearward “ears” off the 5015 fans for clearance.
  - OscarGM was able to get the standard length ducts (found in the 2.4 folder) to clear. It looked tight, but it did clear.
  - The ducts in the 1.8 folder have 2mm extra clearance, and should clear with most fans.
  - The reason 1.8 needs the ears cut is because the duct start to look ridiculously long due to the inverted nature of the 1.8 gantry.
- Acknowledgements:
  - Just wanted to thank GarretWP, OscarGM, and Koonweee for being the brave souls to test and work with me to get it working with 1.8.
 <table width=100% border=0>
 <TR>
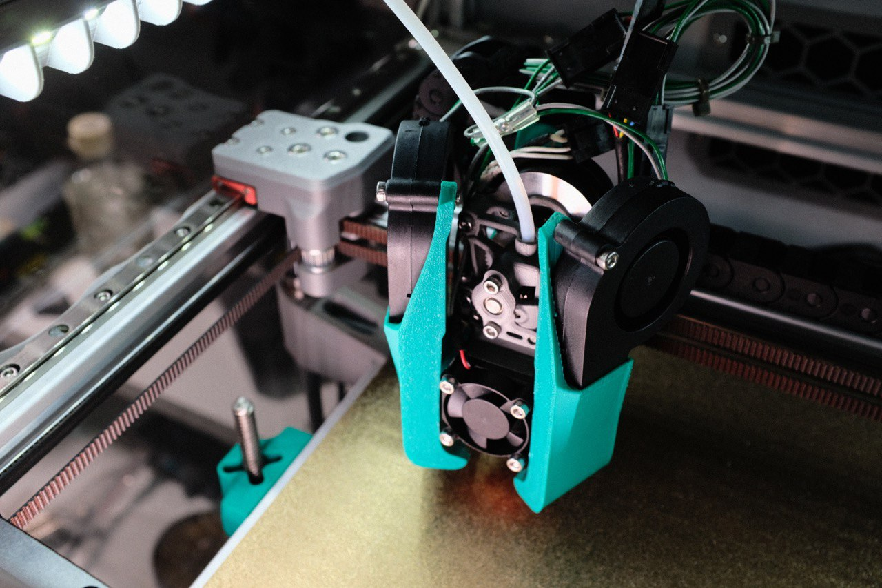
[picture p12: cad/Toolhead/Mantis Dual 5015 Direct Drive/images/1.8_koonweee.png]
 <TD align="center" width=50%> </TD>
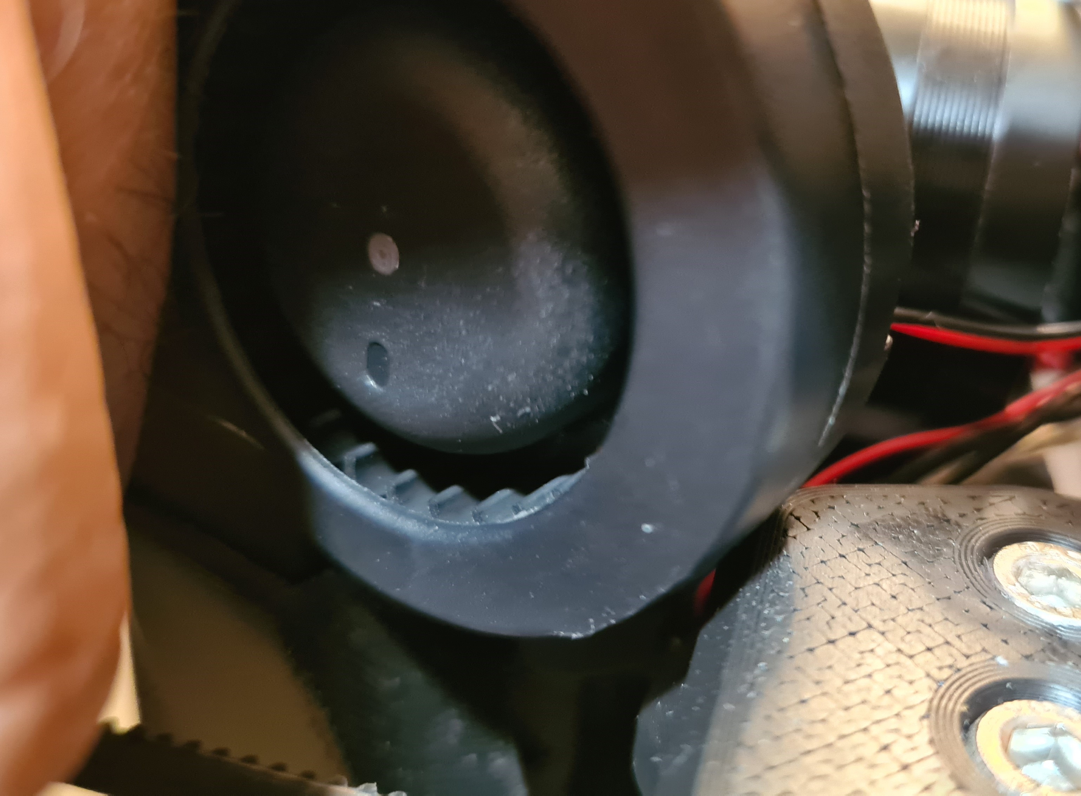
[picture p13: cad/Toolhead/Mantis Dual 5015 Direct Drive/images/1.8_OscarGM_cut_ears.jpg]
  <TD align="center" width=50%> </TD>
 </TR>
 <TR>
 <TD align="center" width=50%>Koonweee’s Voron 1.8 using 2mm extended ducts</TD>
 <TD align="center" width=50%>OscarGM’s Voron 1.8 with 2.4 ducts (clearance by cutting the 5015 ears)</TD>
 </TR>
 </table>

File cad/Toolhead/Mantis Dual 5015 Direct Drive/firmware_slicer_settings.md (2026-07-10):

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

Firmware Settings
============
- **note that all these settings are based on my printer which is a Voron 300. Your settings may vary from mine**
- PWM
  - With my Sunon 5015s I have been able to pwm down to 7% using these settings

       ```
       kick_start_time: 0.5
       off_below: 0.05
       cycle_time: 0.008
       ```
       
- Skip First Probe
  - The first probing during QGL/Bed Mesh at each position is generally off and then settles for the following probes.  Many people do multiple probes then take the median value.  Another option is to use "ignore first probe" by CTSO.  
  - https://github.com/ctso/klipper/commit/75beccd22a70b49b50ae20391b5c0054113eb7b7 
 
 - [probe] settings

       [probe]
       # Mag Probe
       x_offset: -1.95 #This will be +1 or -1 depending on which way the nub on your  magprobe microswitch is oriented.
       y_offset: 32.95
       z_offset: 2.4
       speed: 5
       samples: 3
       sample_retract_dist: 1.5
       samples_tolerance: 0.006
       samples_tolerance_retries: 5
       drop_first_result: true #only used if you’re using the ignore first probe.
       
- Homing override to home y before x.
  - To avoid collision with the ducts with the front idlers.  This is less of an issue these days with narrow idlers released.

       ```
       [homing_override]
       axes: z
       set_position_z: 0
       gcode:
       G90
       G0 Z5 F600 # move up a little for clearance
       G28 Y
       G28 X
       G0 X200 Y305 F3600 # home on z pin at this location (CHANGE THIS TO YOUR OWN ENDSTOP LOCATION)
       G28 Z
       G0 Z10 F1800 # move up a little for clearance
       G0 X150 Y150 Z30 F3600 # Go to middle of bed
       ```

Slicer settings
============
- This is currently what I’ve been using for ABS as far as cooling with my Sunon 5015s. Not sure where I’ll end up here, but it’s a starting point.
- I increase default fan speed to 20% if the part has a lot of overhangs
- Don’t be afraid to pump the fan up with ABS, especially for overhangs and short layer times. 
  - The higher fan percent will increase your chamber temps and offset the higher fan usage. 
  - I often see 55c+ chamber temps in my uninsulated Voron 300. 
  - If I’m printing a single ABS part with short layer times I’ll often use 50%+ fan for the whole part. I haven’t had issues with layer splitting when I do this.  

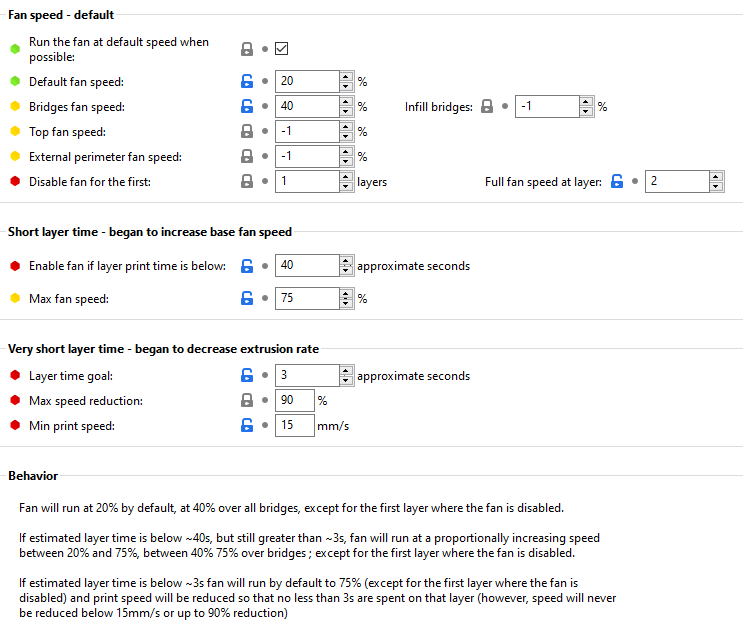
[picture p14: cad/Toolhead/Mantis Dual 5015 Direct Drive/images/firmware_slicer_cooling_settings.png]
Slicer Settings


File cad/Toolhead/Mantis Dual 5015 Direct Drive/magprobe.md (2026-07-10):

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

Mag Probe 
============
- Magprobe Assembly
  - Solder a short length of flexible wire to two m6x3 magnets then press the magnets into the holes.
  - When pressing in the magnets, I used a clamp and a flat surface to try to get the magnets flat.
  - Screw in two of the m2x10 or m2x12 self-tapping screws (silver ones on the red pictured magprobe below) prior to soldering the microswitch in. Take care not to damage the wires.
  - Solder the other ends of the wires to the outer prongs (NC) of the microswitch. Note the image with the black magprobe is an older version.
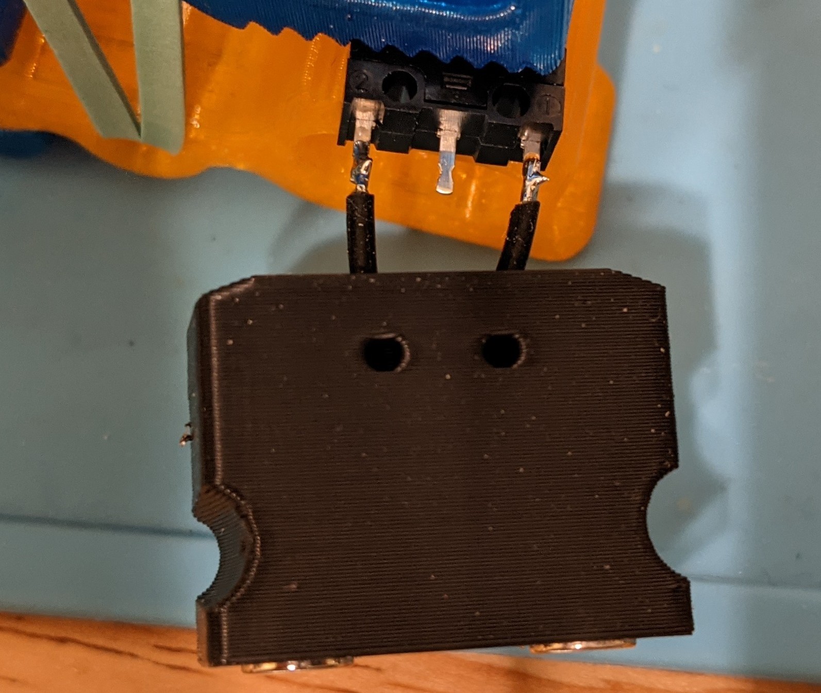
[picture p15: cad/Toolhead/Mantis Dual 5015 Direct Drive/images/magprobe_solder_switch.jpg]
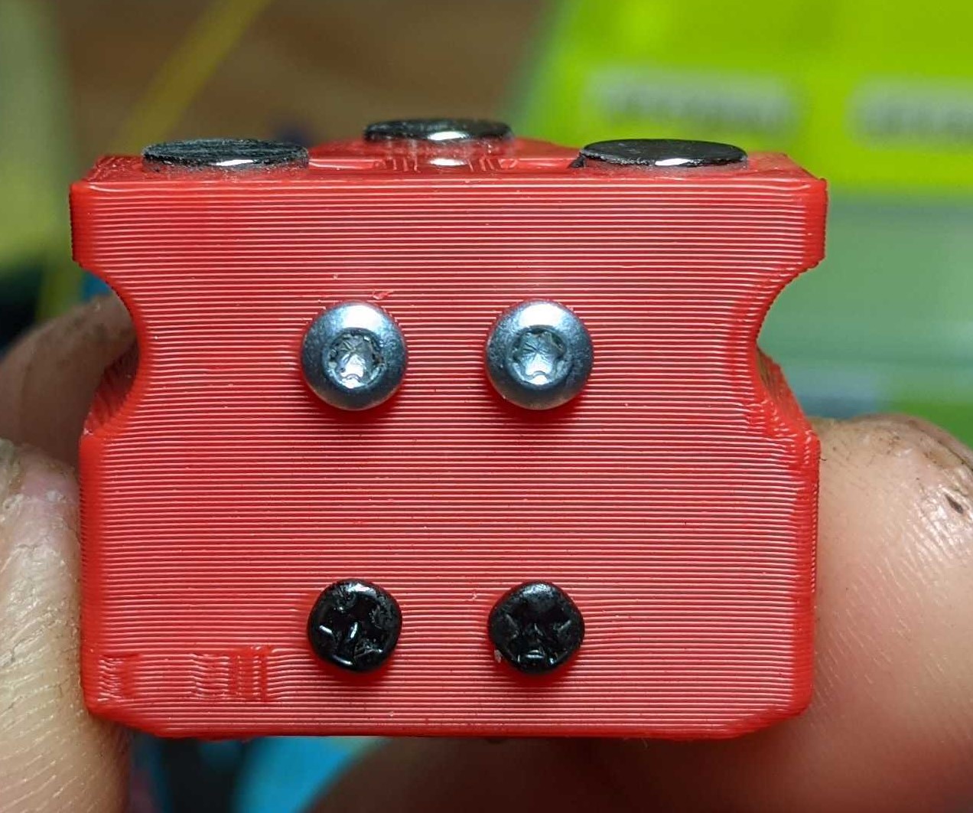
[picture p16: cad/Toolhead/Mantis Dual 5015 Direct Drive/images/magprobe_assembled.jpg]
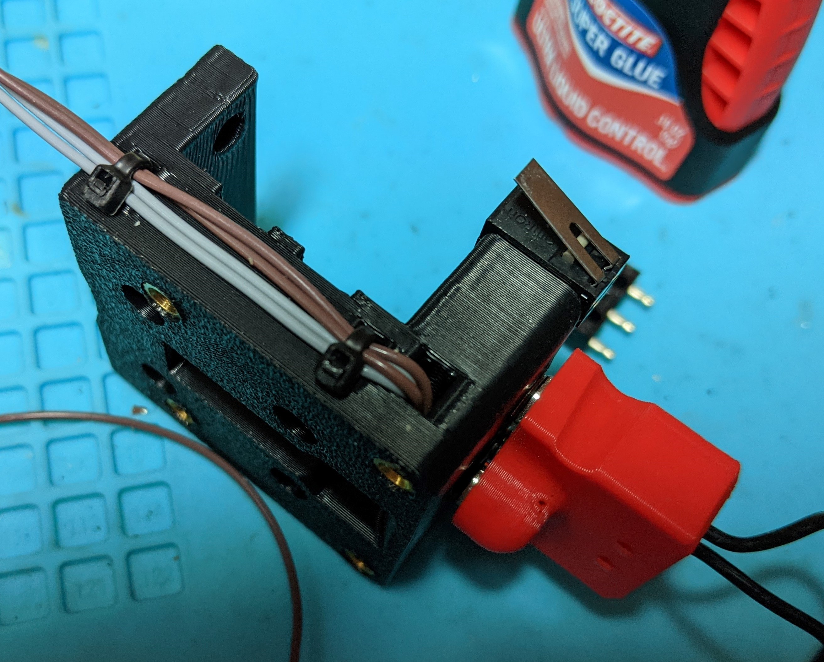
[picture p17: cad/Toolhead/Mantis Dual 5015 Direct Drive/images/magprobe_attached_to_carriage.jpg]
  - 
  - Press in the microswitch now and screw in two more m2x10 or m2x12 to secure the microswitch. If there is any play in the microswitch, use some superglue to remove the play.
  - Test fit the magprobe to the carriage and adjust the level of the probe using the m3x6 button head on the bottom of the carriage.
  - Insert magnets into dock arms and secure to bed extrusion or gantry extrusion.
  - You don’t have to remove your bat85 diode when wiring in the wires to the magnets on the carriage, just omit the 24v.
- Dock Assembly
  - Gantry Mounted
    - This is generally the most popular version of the mount.  It is easy to set up and you don't have to worry about your z-offset when attaching and docking the probe.  
    - Note that the red magprobe in the gantry dock photos is the longer variant for rapido and crazy volcano.

    - 

    - Print the dock mount, extrusion mount, and either of the dock arms. 
      - Depending on your machine and the m2 screws you used on your mag probe, you may need the double magnet version of the dock arms.  I am using the single magnet version and I havent had the magprobe fall out during printing yet.  However some poeple have needed the double version.  I would say start with the single magnet version then swap to the double if necessary.
    - Height
      - This is straightforward. Adjust the height so the probe lines up with the arms.
    - Forward Reach 
      - I have my dock adjusted so that the magprobe, when docked, is actually a few mm further back (+y) than where the magnets of the carriage can reach.  
        - For example.  If the carriage magnets are at y305.  Then the mag probe magnets, when in the dock, can be at around y308 (out of the actual moveable range of the printer)
      - When picking up the probe, the mag probe will snap forward to the carriage magnets.  
      - When dropping off the probe, as the toolhead moves to the side, the mag probe will snap back to the dock.  
      - This allows you to have the magprobe just a few more mm out of your printing area.  

  - Bed Mounted
    - Bed mounted dock also works well.  Just a matter of personal preference.

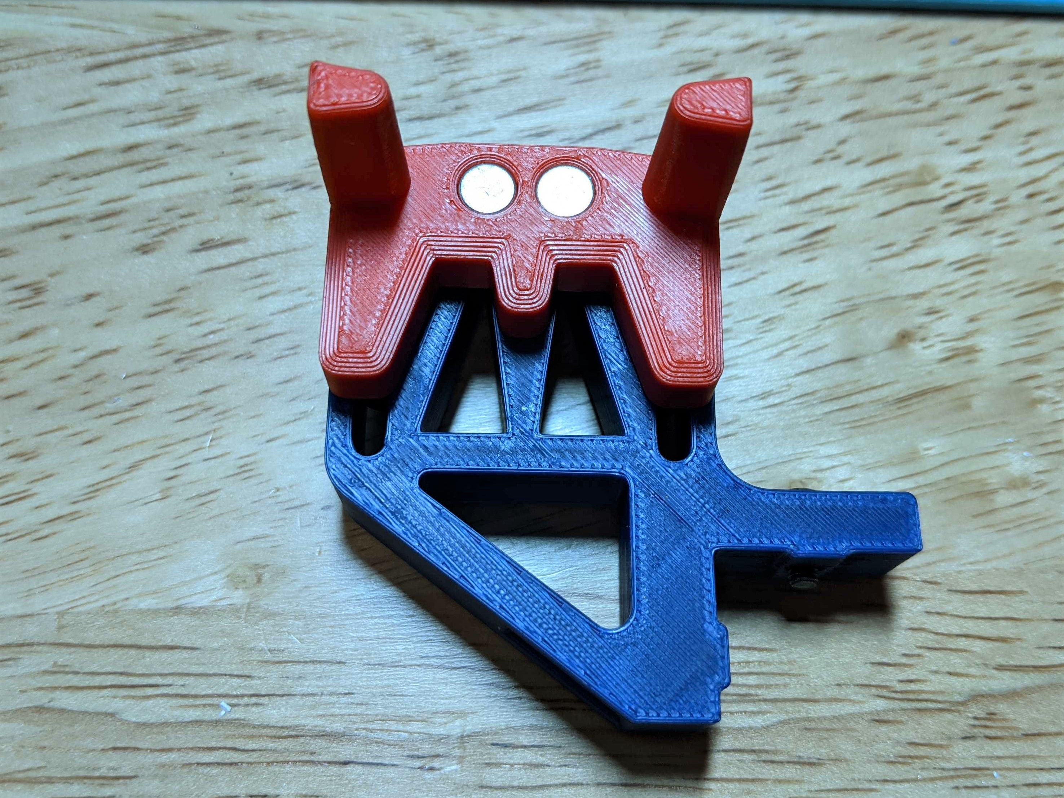
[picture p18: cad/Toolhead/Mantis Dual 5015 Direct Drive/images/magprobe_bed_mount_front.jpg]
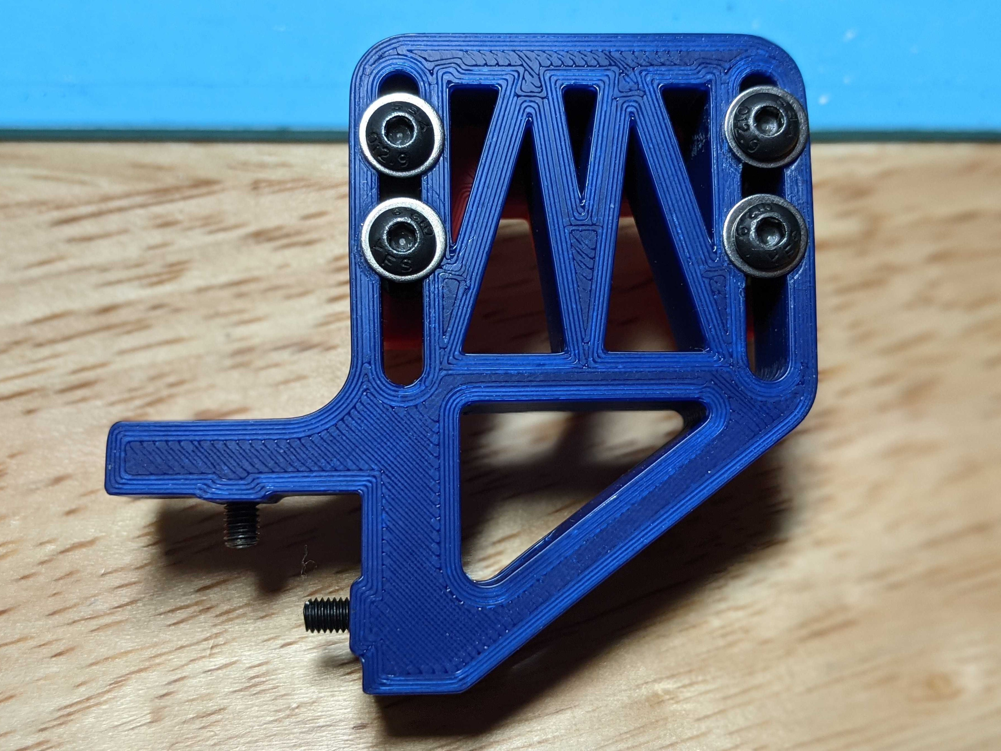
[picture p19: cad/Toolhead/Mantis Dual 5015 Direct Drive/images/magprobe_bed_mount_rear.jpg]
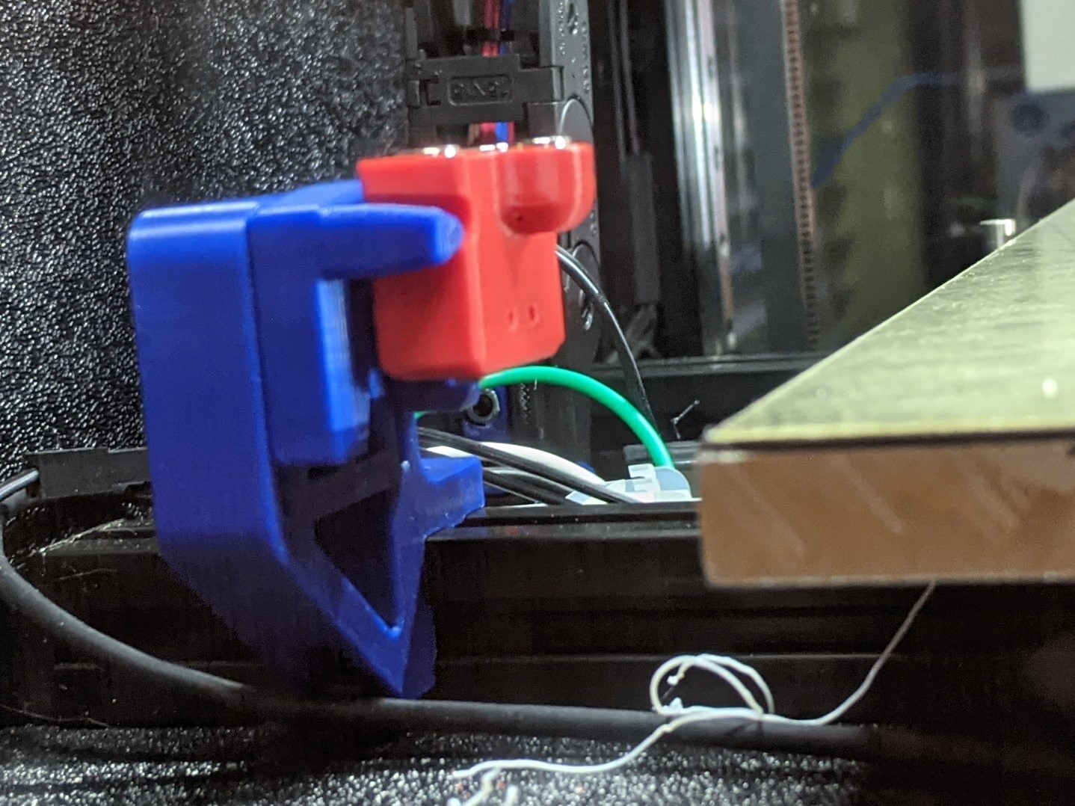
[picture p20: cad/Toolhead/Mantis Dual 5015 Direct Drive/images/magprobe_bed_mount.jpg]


- Magprobe Config
  - This seems pretty daunting to do…but it's not as bad as you think.  Check out the klicky or annex macros linked below.  
  - I highly recommend you print extra dock arms while you are figuring this out—especially if you are doing bed extrusion mounted.
  - Don’t forget to home y before x in homing_override.
  - For smart macros
    - Annex repo for their magprobe at  https://github.com/Annex-Engineering/Annex-Engineering_Other_Printer_Mods/tree/master/All_Printers/Microswitch_Probe
    - Klicky probe repo at https://github.com/jlas1/Klicky-Probe

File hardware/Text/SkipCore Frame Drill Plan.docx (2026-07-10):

vSlot 20 x 40

# | Size | Length (mm) | Qty | Description | Picture

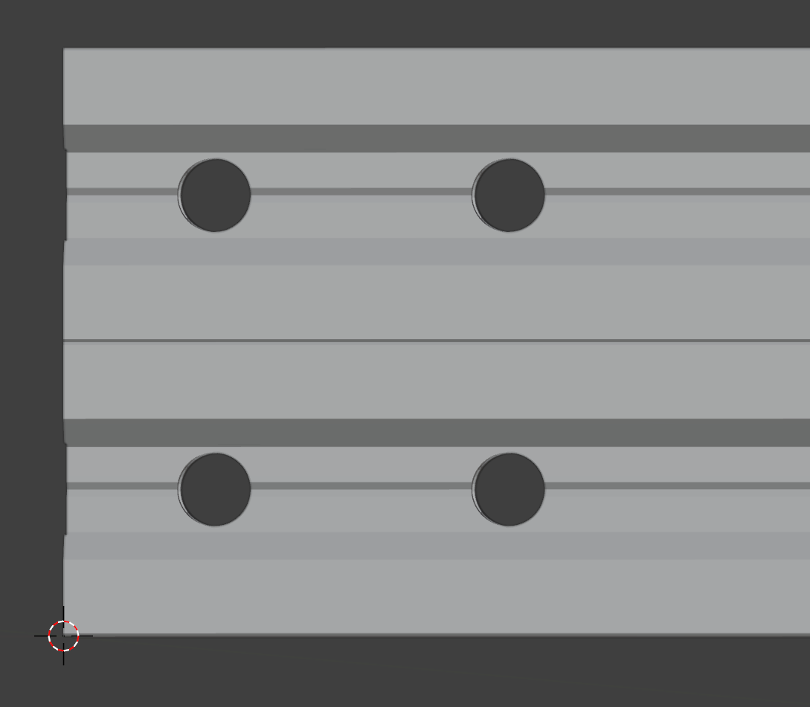
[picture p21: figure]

| 20 x 40 | 550 | 4 | 10mm in and 20 x0 20 centres Each end

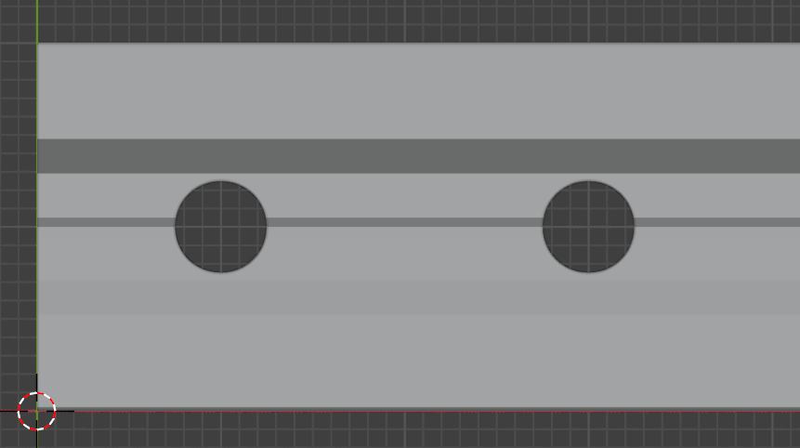
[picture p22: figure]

| 20 x 40 | 550 | 4 | On the same pieces as above

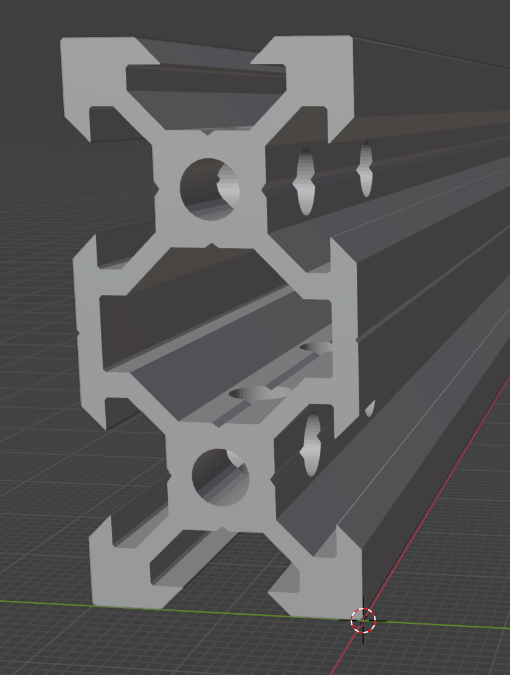
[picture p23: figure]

| | | | Result

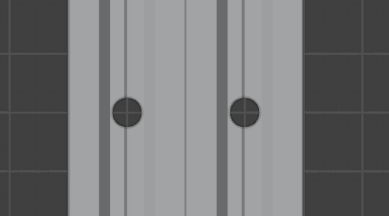
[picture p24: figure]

| 20 x 40 | 500 | 4 | Two holes at exactly 410mm


| 20 x 40 | 500 | 4 | Same pieces as 3 One hole horizontally at exactly 410mm


| | | | Result
| 20 x 40 | 460 | 2 | One vertical hole across the 40mm 400mm from one end. TO BE DETERMINED AFTER INITIAL BUILD | Bottom side rails
| 20 x 40 | 460 | 2 | One vertical hole across the 20mm on one side only away from the linear rail 400mm from one end. TO BE DETERMINED AFTER INITIAL BUILD | Upper Y carriage side rails

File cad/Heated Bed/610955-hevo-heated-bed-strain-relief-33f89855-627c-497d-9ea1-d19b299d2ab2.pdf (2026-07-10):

3D MODEL ONLY

### Summary

Added strain relief for the HEVO (or any 2020 frame). Useful for AC heated beds/ any heated beds. The distance from...

3D Printers (https://printables.com/model?categoryId=1) > Other Printer Parts & Upgrades (https://printables.com/model?categoryId=2)

Tags: hypercube | thingiverse | hevo | hce

Added strain relief for the HEVO (or any 2020 frame). Useful for AC heated beds/ any heated beds.

The distance from the 2020 frame to the cable groove is approximately 13mm.

The offset from the frame is 20mm.

Secured using 1 M5 drop in nut and screw.

The wires are secured using 2 small zipties.

Category: 3D Printer Parts

printwithmeXYZ (https://printables.com/@printwithmeXY_827190)

## HEVO Heated Bed

## Strain Relief

VIEW IN BROWSER (https://printables.com/model/610955-hevo-heated-bed-strain-relief)

updated 11. 10. 2023 | published 11. 10. 2023

## Model files

Find source .stl files on Thingiverse.com (https://www.thingiverse.com/thing:4378474)

### License

This work is licensed under a
Creative Commons (4.0 International License)

Attribution (http://creativecommons.org/licenses/by/4.0/)

✖ | Sharing without ATTRIBUTION
✔ | Remix Culture allowed
✔ | Commercial Use
✔ | Free Cultural Works
✔ | Meets Open Definition

hevo_strain_relief_v5.stl

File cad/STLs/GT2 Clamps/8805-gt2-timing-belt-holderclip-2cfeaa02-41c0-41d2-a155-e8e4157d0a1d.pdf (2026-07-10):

## GT2 Timing Belt Holder/Clip

0.26 hrs; 1 pcs; PET; Prusa; Summary; Tags: upgrade; prusa; holder; motor; printer; clip; mount; anet; lock; stepper; belt; easy; snap; cnc; smart; fixture; xbelt; tensioner; clamp; reprap; xaxis; belttensioner; fiber; gt2belt; fix; pulley; aneta8; thingiverse; beltclip; simple; aneta6; aneta6upgrade; beltholder; beltclamp; gt2beltclip; timing; timingbelt; timingbelts; elegant; gtbelt; Area51; updated 5. 12. 2023 | published 5. 12. 2023

VIEW IN BROWSER (https://printables.com/model/8805-gt2-timing-belt-holderclip)

Simple and easy GT2 Timing belt holder/clip

3D Printers (https://printables.com/model?categoryId=1) > Other Printer Parts & Upgrades (https://printables.com/model?categoryId=2)

The GT2 Timing Belt Holder/Clip is a simple and efficient solution for most
3D printer projects. It is designed to securely hold GT2 timing belts, which
are commonly used in 3D printers and other CNC machines.

## Model files

The model comes in two versions to accommodate both thin and thick GT2 belts, providing flexibility based on the specific requirements of your project. The part shown here is printed in PETG, that has high durability.

>> Please leave a like and make me happy... :) Thank you!

### Print instructions

Layer height: 0.20mm
Infill: 25%

2 perimeters, 3 top and 2 bottom layers.

3mf file has settings and both models.

## This remix is based on

GT2 Timing Belt Holder/Clip, Upgrade

by Area51

GT2 Timing Belt Holder/Clip, Upgrade

by Area51 (https://www.thingiverse.com/thing:2354961)

x-belt-holders.3mf

x-belt-holder-gt2.stl

## Print files

h PET | k 0.40 mm | f 0.20 mm | 0.26 hrs | 1 g | d Prusa MK3/S/S+

Find source .stl files on Thingiverse.com (https://www.thingiverse.com/thing:2354961)

## License

This work is licensed under a
Creative Commons (4.0 International License)

Attribution-ShareAlike (http://creativecommons.org/licenses/by-sa/4.0/)

✖ | Sharing without ATTRIBUTION
✔ | Remix Culture allowed
✔ | Commercial Use
✔ | Free Cultural Works
✔ | Meets Open Definition

x-belt-holder-thin-gt2.stl

x-belt-holders_02mm_pet_mk3s_15m.gcode

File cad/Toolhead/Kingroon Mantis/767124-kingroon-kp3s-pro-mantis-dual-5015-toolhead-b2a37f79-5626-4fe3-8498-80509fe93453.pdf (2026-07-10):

## kingroon KP3S PRO

## Mantis dual 5015

Summary; Tags: volcano; sherpa; sherpamini; volcanohotend; chcpro; BLtouch offset:; x_offset: 26.6; y_offset: 9; Kevin; toolhead; updated 16. 2. 2024 | published 16. 2. 2024; 3D MODEL ONLY

VIEW IN BROWSER (https://printables.com/model/767124-kingroon-kp3s-pro-mantis-dual-5015-toolhead)

kp3s dual 5015 toolhead with bltouch mount and sherpa mini extruder. It
supports a volcano, CHC pro or rapido HF hotend

3D Printers (https://printables.com/model?categoryId=1) > Other Printer Parts & Upgrades (https://printables.com/model?categoryId=2)

if you need any other combination you can go here to the original one.
https://mods.vorondesign.com/details/X1OtCg3ZJQBmZ7LEU7LqQ

This remix is based on

## Model files

Mantis Dual 5015 Toolhead by Long (https://mods.vorondesign.com/detail/X1OtCg3ZJQBmZ7LEU7LqQ)

mount.stl

duct_brace_rapido_crazy_volcano_clamp_left_v11.stl

duct_brace_rapido_crazy_volcano_clamp_right_v11.stl

duct_brace_rapido_crazy_volcano_full_v12_open_mount.stl

duct_rapido_hf_v003b_right.stl

duct_rapido_hf_v003b_left.stl

hotend_mount_rapido_v03.stl

## License

This work is licensed under a
Creative Commons (4.0 International License)

Attribution (http://creativecommons.org/licenses/by/4.0/)

✖ | Sharing without ATTRIBUTION
✔ | Remix Culture allowed
✔ | Commercial Use
✔ | Free Cultural Works
✔ | Meets Open Definition

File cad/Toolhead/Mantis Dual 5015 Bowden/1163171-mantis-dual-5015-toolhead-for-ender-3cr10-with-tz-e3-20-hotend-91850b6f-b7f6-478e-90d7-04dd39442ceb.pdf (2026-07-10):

3D MODEL ONLY

## Summary

Mantis Dual 5015 Toolhead for Ender 3/CR10 with TZ E3 2.0 Hotend

3D Printers (https://printables.com/model?categoryId=1) > Creality Parts & Upgrades (https://printables.com/model?categoryId=135)

Tags: | upgrade | mod | hotend | creality | ender | cooling
ender3 | crealityender3 | ender3pro

Upgrade your Ender 3 or CR10 with the Mantis Dual 5015 Toolhead, designed for the TZ E3 2.0 hotend and enhanced cooling. This toolhead features dual 5015 blower fans and a 3010 fan, providing exceptional airflow and cooling performance for superior print quality.

Key Features:

Fan Upgrades Required: Replaces the existing hotend and part cooling fans with 2x 5015 blower fans and a 3010 fan for powerful and efficient cooling.
Parallel Blower Fans: Two 24V blower fans wired in parallel for the Ender 3. More powerful fans allow for lower speeds depending on your print speed and material, offering flexibility for various projects. Optimized Ducts: Lengthened ducts to ensure 5015 blower fans clear the Ender 3 Pro carriage back plate.

Kvothe (https://printables.com/@Kvothe_2582960)

## Mantis Dual 5015 Toolhead for Ender 3/CR10 with TZ E3 2.0 Hotend

VIEW IN BROWSER (https://printables.com/model/1163171-mantis-dual-5015-toolhead-for-ender-3cr10-with-tz)

updated 7. 7. 2025 | published 7. 7. 2025

•

•

•

## Model files

Secure Mounting: The duct mount features countersunk M3 nut sections for secure and stable mounting.
MK8 Compatibility: Duct mount attaches to the hotend via mounting bolts, making it compatible with MK8 hotend mounting points.
BLTouch Mount: Includes a custom BLTouch mount designed to fit the Ender 3 carriage behind the duct. BLTouch coordinates are x_offset: -40 y_offset: 1

Note: This design is open-source under the GPL v3.0 license, allowing for personal and commercial use.

## This remix is based on

VoronUsers/printer_mods/Long/Mantis_Dual_5015 at main · VoronDesign/VoronUsers (https://github.com/VoronDesign/VoronUsers/tree/main/printer_mods/Long/Mantis_Dual_5015)

- No supports needed
- No supports needed

•

•

•

mantisdual5015_tze3_ender3_cr10_mod_duct_right.stl

mantisdual5015_tze3_ender3_cr10_mod_duct_left.stl

mantisdual5015_tze3_ender3_cr10_mod_mount.stl

mantisdual5015_tze3_ender3_cr10_mod_bltouch_mount.stl

## License

This work is licensed under a GNU

General Public License v3.0 (https://www.gnu.org/licenses/gpl-3.0.html)

✖ | Sharing without ATTRIBUTION
✔ | Remix Culture allowed
✔ | Commercial Use
✔ | Meets Open Definition
ℹ | Share under the same license

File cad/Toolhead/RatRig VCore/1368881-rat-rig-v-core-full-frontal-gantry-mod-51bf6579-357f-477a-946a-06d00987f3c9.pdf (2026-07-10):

## Rat Rig V-Core Full Frontal Gantry

Summary; Tags:; dragon; mod; rat; core; ace; rig; gantry; full; ratrigvcore; ratrig; ultralight; ratrigvcore3; mfbs; frontal; ratrigvcore31; MFBS Design; mod.; updated 15. 9. 2025 | published 15. 9. 2025; 3D MODEL ONLY

VIEW IN BROWSER (https://printables.com/model/1368881-rat-rig-v-core-full-frontal-gantry-mod)

Full Frontal X gantry mod for Rat Rig V-Core 3/3.1

3D Printers (https://printables.com/model?categoryId=1) > Other Printer Parts & Upgrades (https://printables.com/model?categoryId=2)

The Full Frontal Gantry mod for all models of Rat Rig V-Core 3 and 4
printers, other than IDEX.
Compatibility:
V-Core 3
V-core 3.1
V Core 3 and 3.1 MFBS upgrade
V-Core 3.2h
V-Core 4
V-Core 4 hybrid
OneBox and
Enclosure 2
All Ultralight print heads.

Please note initial testing of this mod has been completed.
Why

The Full Frontal Gantry mod dramatically reduces the distance of the nozzle from the Centre of Rotation of the MGN12 carriage in the Y and Z dimensions. reducing nozzle movement due to play/flex in the carriage rail mounting interface to increase printing precision.
The The Full frontal mod also dramatically reduces the distance from the belt attachment points from the Centre of Rotation of the MGN12 carriage in both the Y and Z dimensions, reducing the moment of torque applied by the belts to the Centre of Rotaion of the MGN12 carrigage to increase printing precision.
The Ultralight core mounting plate template will provide a simple fixutre for a variety of print tools. Print tools could be things like the upcoming Bondtech INDA a pen a drag knife, etc.

Coffee fund
I receive no kick backs or royalties from third party companies such as Funssor and PCBway who manufacture and sell stuff I design and post on Printables.
If you decide to make a donation to my coffee fund (which keeps me up late at night doing more of this stuff) I would appreciate it. There is absolutely no obligation for you to do this. My PayPal account is Liam@FastBikeGear.co.nz

Please remember to post feed back as it is always valuable to me for future iterations.
Many thanks.
Liam Venter
MFBS Design

A STEP file of the Ultralight Core tool head mounting plate is included for those who want to mount other print heads or tool changers.
The core mounting plate is easily modified to support the mounting of a range of tools and print heads. I will release a version of this mounting plate to suit the Bondtech INDX tool changer as soon as Bondtech release the mounting template.
The Ultralight Core tool head mounting plates should be CNC'd or 3D printed in alumimium. PCBway charge about $26 to print these.
Files for the Dragon Ace Ultralight tool head are included. PCBway charge about $32 to print the Ultralight Dragon Ace for Triangle Labs superb Dragon Ace hot end from aluminium.
Files for the Rapido 2 Ultralight tool head are included.
PCBway charge about $32 to print the Ultralight Dragon Ace for Triangle Labs superb Dragon Ace hot end from aluminium. I highly recommend the use of Funssors optional stand off tube kit with this version of the

1.

2.

3.

Ultralight.

Modular back plate.
I have made the back plate modular.
1. Top (includes unmbilical cable mount
2. CPAP pipe
3. Ducts for part cooling.
Making these three parts modular makes it easier to swap these out for alternative part cooling options.
I have also created drafts of of other Ultralight print heads for the following hot ends that I will update when they are finished.
Phaetus Rapido (original)
Phaetus Rapido 2
Triangle Labs Rapido Ace
Peopoly Lancer
Belt Wedge-Lock retaining system.
For the Ultralight tool heads, I have devised a new belt wedge lock retention system.

The belts are pushed all the way through curved and tapered slots., Then a short 8mm length of filament is placed in about the 4th belt groove from the end,
The belt is then withdrawn out of the slot until the filament and belt jams in the narrowing taper of the slot.,
A small section of belt is left protruding out the slot so that when you want to release the belt you can just pull on the section sticking out with a pair of pliers to release the short piece of filament and then fully with draw the belt from the slot.,

Pros:
I have tested this and it is extremely secure.
Simple, compact and does not require any screws.
Cons:
A little bit fiddly to fit, but probably quicker than most other systems.
I did experiment with using a toothed wedge instead of a piece of filament, but the filament worked so well the toothed wedge was just an unnecessary complication and easy part to drop on the floor and loose....so is the filament...but you can always find another 8mm long piece of filament! (edited)
Full Metal XY joiners
While all parts of this design have a non commercial license, I may offer a license to one manufacturer (yet to be selected) to offer these for sale as per the XY joiners for my previous V-Core 3 hybrid upgrade.
XY joiners BOM
2 x M5 x 28 Flat Head Cap screws. (Ganty retaining top)
2 x M5 x 10mm Socket Head Cap screws. (Gantry retaining bottom) 7 x M3 x 8mm flat head cap screws (bearing stack retaining)

1.
2.

3.

4.

## Model files

1 x M3 x 6 mm flat hed cap screw for (bearing stack retaining)
4 x Aluminium threaded spindles 14 x 50D x 3mm ID (centre of bearing stack).
Assembly.
XY Joiners:
The two of the bearing stacks mounted in the shorter clevis's must be installed before the gantry is fitted. They can not be installed after the gantry is fitted. These will only fit into place if installed from behind the XY joiners. It is not possible to access the rear of the XY joiners once the gantry is intalled.
The other two bearing stacks can be fitted before or after the gantry is installed.
Ultralight:
Depending on the accuracy of the aluminium printed part, whichg can vary by as much as 0.1mm you may need to fractionally open up the entry point for the belt slots. This can be easily accomplished with a 1.5 mm drill bit.

Updates
8/Sept/2025 increased diameter of heat sink hole in Dragon Ace version of Ultralight print head to make fitting easier.
8/Sept/2025 Increased clearances on XY joiners for belts.
14/Sept/2025 further increased the clearances on the XY joiners for the belts.
15/Sept/2025 Published Rapido 2 Ultralight STL and STEP files.
Still do do:
Improved version of the part cooling duct. The improved version will include my normal vertical splitter in each horn of the duct. This should be done in a couple of days.
Ultralight mount for Bondtech INDX.

rapido-2-ultralight-v24.stl

rapido-2-ultralight-v24.step dragon-ace-ultralight-v184.stl

dragon-ace-ultralight-v184.step

ultralight-core-template-v184.stl

ultralight-core-template-v184.step

bearing-stack-threaded-tube.stl

bearing-stack-threaded-tube.step

back-plate-top-v99.stl

back-plate-top-v99.step

cpap-pipe-v99.stl

cpap-pipe-v99.step

part-cooling-duct-v99.stl

part-cooling-duct-v99.step

x-stop-bumper-v10.stl

x-stop-bumper-v10.step

right-xy-joiner-cosmetic-v6.stl

right-xy-joiner-cosmetic-v6.step

l-front-ffg-xy-joiner-v69.stl

l-front-ffg-xy-joiner-v69.step

r-front-ffg-xy-joiner-v53.stl

r-front-ffg-xy-joiner-v53.step

## License

This work is licensed under a
Creative Commons (4.0 International License)

Attribution-NonCommercial (http://creativecommons.org/licenses/by-nc/4.0/)

✖ | Sharing without ATTRIBUTION
✔ | Remix Culture allowed
✖ | Commercial Use
✖ | Free Cultural Works
✖ | Meets Open Definition

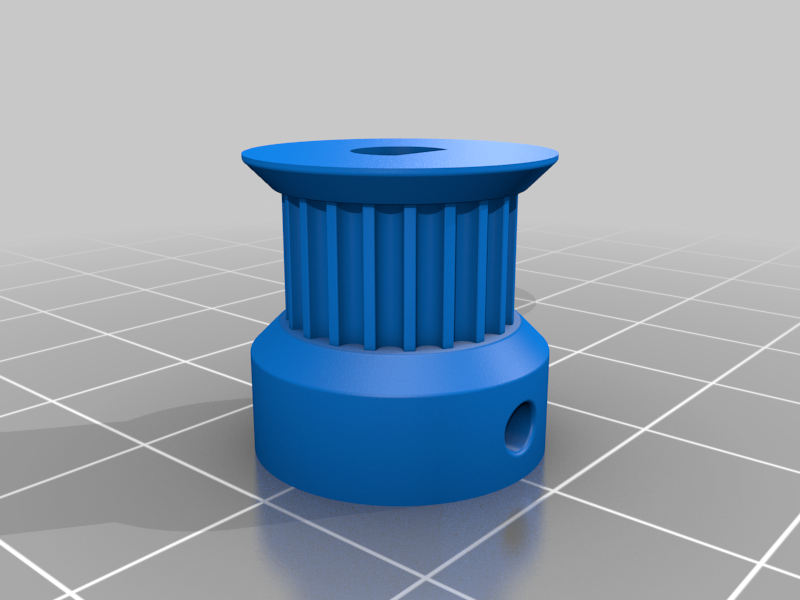
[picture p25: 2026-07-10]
hardware/CAD/GT2 Timing Belt Pulley/images/833d7fce79abef64efee6d2599f4a7bc.png

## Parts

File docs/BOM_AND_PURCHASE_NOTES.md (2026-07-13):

# SkipCore350 BOM and Purchase Notes

This document is the human-readable companion to the spreadsheet BOM.

Use it for purchase source notes, AliExpress/eBay/Amazon/local substitutions, mistakes, and practical comments that do not fit neatly into a spreadsheet cell.

---

## Linked BOM file

Current spreadsheet location in repo:

```text
hardware/SkipCore350_BOM_with_STL_Links.xlsx
```

Keep the spreadsheet as the structured source of truth for quantities, sizes, and links. Use this Markdown file for narrative build notes.

---

## Core architecture summary

```text
Printer: SkipCore350
Motion: CoreXY
Target build volume: 350 x 350 x 350 mm
Frame: 2020 / 2040 aluminium extrusion
Linear rails: MGN12 / MGN12H style
Belts: GT2, 9 mm
Z: triple Z leadscrew system
Controller: BTT Manta M8P v2.0 with CB1
Drivers: TMC2209
Bed: 350 x 350 x 8 mm aluminium tooling plate
Bed heater: 230 VAC silicone heater, around 500 W
Current hotend: E3D Revo Ceramic 24 V 60 W
Alternate/planned hotend: Rapido 2 UHF PT1000
Extruder: HGX Lite 2.0 style, direct drive/Bowden path depending on current build stage
Probe: BLTouch
```

---

## Purchase-source categories

Use these sections to record where each major component came from and whether it was a good purchase.

### AliExpress

| Item | Supplier/store | Link | Qty | Status | Notes |
|---|---|---|---:|---|---|
| 9 mm GT2 belts | | | | | |
| Idlers/pulleys | | | | | |
| MGN12 rails | | | | | |
| TMC2209 drivers | | | | | |
| HGX Lite extruder | | | | | |
| Fans | | | | | |
| Cable chain | | | | | |
| Fasteners | | | | | |

### eBay

| Item | Seller | Link | Qty | Status | Notes |
|---|---|---|---:|---|---|
| | | | | | |

### Amazon

| Item | Seller | Link | Qty | Status | Notes |
|---|---|---|---:|---|---|
| | | | | | |

### Local / Australian suppliers

| Item | Supplier | Link | Qty | Status | Notes |
|---|---|---|---:|---|---|
| Aluminium bed plate | | | | | |
| AC silicone heater | | | | | |
| Thermal fuse | | | | | |
| Wiring / ferrules / terminals | | | | | |
| Fasteners | | | | | |

---

## Parts to verify before public recommendation

- [ ] Exact Manta M8P v2.0 source.
- [ ] Exact CB1 source.
- [ ] Exact rail lengths.
- [ ] Exact belt length and pitch.
- [ ] Exact idler/pulley tooth and bore details.
- [ ] Exact AC bed heater wattage and supplier.
- [ ] Exact bed thermistor type.
- [ ] Exact SSR model and rating.
- [ ] Exact fans and voltage.
- [ ] Exact extruder model and gear ratio.
- [ ] Exact hotend version and sensor.

---

## Good purchase / bad purchase log

### Good purchases

| Item | Why it was good | Would buy again? |
|---|---|---|
| | | |

### Problem purchases

| Item | Problem | Workaround / replacement |
|---|---|---|
| | | |

---

## Notes on substitutions

When documenting alternatives, include:

```text
Original intended part:
Actual purchased part:
Reason for substitution:
Mechanical impact:
Firmware/config impact:
STL/CAD impact:
Would recommend to another builder: yes/no
```

---

## Open BOM tasks

- [ ] Link each STL to the matching BOM row where practical.
- [ ] Mark parts as purchased / printed / installed / replaced.
- [ ] Add source links for AliExpress, eBay, Amazon, and local suppliers.
- [ ] Add notes for parts that needed modification.
- [ ] Add a final “known-good build” BOM once commissioning is complete.

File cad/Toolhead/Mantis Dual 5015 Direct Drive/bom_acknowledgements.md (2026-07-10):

<table width=100%>
<TR>
<TD align="center"><B>Link</TD><TD align="center"><B>Description</TD></TR>
<TR><TD align="center"><a href="readme.md">Readme</A></TD><TD align="center">Mantis Description and Updates</TD></TR>
<TR><TD align="center"><a href="bom_acknowledgements.md">BOM and Acknowledgements</A></TD><TD align="center">BOM, links to other repositories, acknowledgements</TD></TR>
<TR><TD align="center"><a href="print_orientation.md">Print Orientation</A></TD><TD align="center">Printing the parts</TD></TR>
<TR><TD align="center"><a href="carriage_assembly.md">Carriage Assembly</A></TD><TD align="center">Building the MGN9, MGN12 Carriage, Hotend Mounts</TD></TR>
<TR><TD align="center"><a href="magprobe.md">Magprobe Assembly</A></TD><TD align="center">Assembly of Mag Probe</TD></TR>
<TR><TD align="center"><a href="firmware_slicer_settings.md">Firmware and Slicer Settings</A></TD><TD align="center">Firmware and Slicer Settings</TD></TR>
<TR><TD align="center"><a href="1.8_trident.md">Voron 1.8 and Trident</A></TD><TD align="center">Notes on Voron 1.8 and Trident</TD></TR>
<TR><TD align="center"><a href="final_assembly.md">Final Assembly</A></TD><TD align="center">Notes and Pictures of final assembly</TD></TR>
<TR><TD align="center"><a href="https://github.com/mandryd/MantisUsermods/tree/main/Usermods">Usermods</A></TD><TD align="center">Mods by Mantis Users (note: separate repository)</TD></TR>
<TR><TD align="center"><a href="https://github.com/mandryd/VoronUsers/tree/master/printer_mods/Long/Mantis_Dual_5015">Long's Mantis Repository</A></TD><TD align="center">Long's Repository for Mantis.  Updates and newest stuff will be found here</TD></TR>
</table>

BOM, Links, and Acknowledgements
============
**BOM:**
- Fasteners
  - m2 x 10 (or m2 x 12) self tapping screws
    - This is a standard Voron part used to attach the Omron microswitches
  - Assorted BHCS and SHCS
    - The only Socket Head screws I used are (2) m3x20 that go into the upper hotend mount holes to attach the hotend mount to the carriage.  
  - m3x5x4 heatsets – Standard Voron heatsets
- Magnets
  - m6x3 magnets (standard Voron magnets)
  - larger diameter magnet stack (not required)
    - used when solding wire to magnets so that magnetic field loss is minimized during soldering.  
    - I bet it's prob ok to not worry about losing magnetic field with soldering because of the non-soldered magnets that are stacked outwards of the soldered magnets.  
- MGN9 Carriage
  - (2) Makerbeam XL m3 T-nuts
    - https://www.amazon.com/gp/product/B06XHQHD4H
  - Alternatively use m3 Openbuild T-nuts
      - https://www.aliexpress.com/item/4000886303032.html
      - These will need to be ground down so they’re around 5.5-6mm wide
    - m3x10mm screws will make threading the belts easier but aren’t required.  
- Microswitches
  - D2F-5 is recommend by Annex
  - I’ve had better luck with cheap KW10 microswitches from Aliexpress
    - https://www.aliexpress.com/item/32829746929.html
  - I've tested at least 3-4 of the D2F-5L (with lever ripped off) microswitches, which were genuine bought from Digikey or Mouser. While using these I would often see random probings which would sound different and give results that were not precise. Since switching to the KW10 switches, my bed probing has been much more precise. Maybe I got a bad batch if D2F-5? Who knows….
-  Fans
     - (2) 5015 fans
        - Sunon MF50151VX-B00U-A99 (12v)
          - https://www.digikey.com/short/zrwpw9
          - Note, make sure it is MF5015V ***X**** the X is important
        - Delta BFB0524HH (24v)
          - Delta: https://www.digikey.com/short/z4b1vtpj
          - Delta slightly better than Sunon >> GDSTime >> Winsinn
      - 3010 Hotend Fan
        - Sunon 3010v1 (12v)
          - This is the fan I tested first and is a great fan with great specs.  I never had any issues with it.
          - This fan is kinda "spinny" but I don't notice it once the panels are on.  
          - https://www.digikey.com/short/t5dpqw4w
        - Sunon 3010v2 (12v)
          - This is a quieter alternative to the 3010v1.  
          - I have been testing this fan lately (a few weeks) and it working fine so far with my dragon/crazy volcano setup printing ABS with chamber temps of 50-60c.  I have not yet tried printing PLA yet with this.  
          -  https://www.mouser.com/ProductDetail/Sunon/MF30101V2-1000UA99?qs=EU6FO9ffTwfZ4Kz3LWY0zg%3D%3D
      - I know of people using winsinn fans and all kinds of random 3010 fans they find in drawers.  They all seem to be working as far as I know.  
        
**References, Acknowledgements:**
- Mini-Sherpa
  - See the Annex guide for its instructions and BOM.
  - https://github.com/Annex-Engineering/Sherpa_Mini-Extruder
  - https://www.youtube.com/watch?v=3WogD5IUwAM
- Mag Probe
  - Credit to ANNEX for their awesome work here on their mag probe.  They deserve a lot of kudos for the idea and implementation of mag probes.   
    - https://github.com/Annex-Engineering/Quickdraw_Probe
  - My version is very similar the Annex Mag Probe.  I remade it to be longer, added a 3rd magnet, and modified the dock arms and dock mating surfaces slightly.  
  - The mag probe and being able to remove the bulk of the Omron probe is a major factor in what made this tool head possible. Please see Annex's mag probe repository for the original.
- HartK Y-Endstop Relocation and Pin Mod
  - I highly recommend relocating the Y-endstop to the a/b drive.  Since the X endstop is on the carriage, this will allow you to remove the endstop pod completely from the right XY joint.  
  - Normal 2.4 version - [https://github.com/hartk1213/MISC/tree/main/Voron%20Mods/Voron%202/2.4/Voron2.4_Y_Endstop_Relocation](https://github.com/hartk1213/MISC/tree/main/Voron%20Mods/Voron%202/2.4/Voron2.4_Y_Endstop_Relocation)
  - [Pin mod](https://github.com/hartk1213/MISC/tree/main/Voron%20Mods/Voron%202/2.4/Voron2.4_Pins_Mod) 2.4 version - [https://github.com/hartk1213/MISC/tree/main/Voron%20Mods/Voron%202/2.4/Voron2.4_Pins_Mod/STLs/Gantry/AB_Drive_Units](https://github.com/hartk1213/MISC/tree/main/Voron%20Mods/Voron%202/2.4/Voron2.4_Pins_Mod/STLs/Gantry/AB_Drive_Units)
  - I also like HartK's Pin Mod.  I'm using it on the A/B joints and XY joints.  I'm using Rama's Front Idlers instead of the pin mod front idlers.  
    - [https://github.com/hartk1213/MISC/tree/main/Voron%20Mods/Voron%202/2.4/Voron2.4_Pins_Mod](https://github.com/hartk1213/MISC/tree/main/Voron%20Mods/Voron%202/2.4/Voron2.4_Pins_Mod)
-  JoshMurrah
   -  Just wanted to note him here as he has been extremely helpful in some insane stress testing. His speed benchies have been fun as hell to watch and a motivation for me to keep improving. His testing has resulted in a lot of improvements to this toolhead.
-  JosAr
   -  Thank you to JosAr for his work on creating a gantry mounted magprobe dock.
- Rama
  - For his version of narrow idlers. 
    - I highly recommend changing your idlers to these while you're changing things out.  This mod will gain you *almost* all all the build area at the front idlers back.  I think it's down to 2mm loss if you use these.
    - https://github.com/Ramalama2/Voron-2-Mods/tree/main/Front_Idlers
- Phalanx
  - For his “Other V2 Idlers” 
    - https://github.com/selliott79/Other-V2-Idlers
- Henrikssn
  - Helping with early testing of the MGN9 carriage.
  - Created an awesome [toolhead board](https://github.com/mandryd/MantisUsermods/tree/main/Usermods/Henrikssn/Toolhead_PCB) and a modified carriage allowing for Klicky compatability.
- BobArctor
  - BobArctor also helped with early single mgn9 testing and test of the Dragon/Crazy Volcano combination
- Wingzero
  - Did a lot of testing/design to get the mosquito hotend working with Mantis
- TheWarolf
  - Modified the hotend mount so that an ERCF sensor would fit and added compatibility with LGX Lite and Sailfin.
  - https://github.com/TheWarolf/Voron-Personal-Mods/tree/main/V2/Long_Mantis_Toolhead
- BeWater, Charles, Dustinspeed, and many others
  - Mantis has been a working collaboration with many people.  Thanks you to everyone who has used Mantis and provided any feedback and usermods.

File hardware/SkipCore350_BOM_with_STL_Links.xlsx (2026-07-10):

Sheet: BOM
Category | Component | Quantity | Size | Notes | Unit Cost AUD | Total AUD | To buy | Buy all | Received | Supplier | URL Links
Frame | 20x40 V-slot | 4 | 550mm | Base/Top Front & Back | $26.79 | $107.16 | $0.00 | $107.16 |  | Aliexpress | 2Pcs Openbuilds 2020 V-Slot Aluminum Profile 100mm-550mm Black/Silver Aluminum Extrusion 20x20mm for CNC 3D Printer Parts - AliExpress 13 (https://vi.aliexpress.com/item/1005007254304843.html?src=bing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)
Frame | 20x40 V-slot | 2 | 460mm | Base Sides | $21.79 | $43.58 | $0.00 | $43.58 |  | Aliexpress | 2Pcs Openbuilds 2020 V-Slot Aluminum Profile 100mm-550mm Black/Silver Aluminum Extrusion 20x20mm for CNC 3D Printer Parts - AliExpress 13 (https://vi.aliexpress.com/item/1005007254304843.html?src=bing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)
Frame | 20x40 V-slot | 2 | 460mm | Y Axis
Frame | 20x40 V-slot | 4 | 500mm | Z Verticals | $12.28 | $49.12 | $0.00 | $49.12 |  | Aliexpress | 1pc Black 2020 2020N1 2040 2040N1 2060 2080 4040 4080 20100 V-Slot Aluminum Profile EU standard 3D Printer Track DIY Frame - AliExpress 13 (https://vi.aliexpress.com/item/1005004679698586.html?scm_id=1007.14452.398466.0&scm-url=1007.14452.398466.0)
Frame | 20x20 V-slot | 1 | 430mm | X Axis
Frame | 20x20 V-slot | 2 | 460mm | Top Sides
Frame | 20x20 V-slot | 1 | 427mm | Bed Support Beam | $10.54 | $10.54 | $0.00 | $10.54 |  | Aliexpress | 1pc Black 2020 2020N1 2040 2040N1 2060 2080 4040 4080 20100 V-Slot Aluminum Profile EU standard 3D Printer Track DIY Frame - AliExpress 13 (https://vi.aliexpress.com/item/1005004679698586.html?scm_id=1007.14452.398466.0&scm-url=1007.14452.398466.0)
Frame | 20x20 V-slot | 1 | 365mm | Bed Support Beam
Motion | MGN12H Rail | 6 | 400mm |  | $18.89 | $113.34 | $113.34 | $113.34 |  | Aliexpress | Cnc Table Kit|miniature Linear Guide Rail Kit Mgn7h-mgn15h For Cnc & 3d Printers (https://vi.aliexpress.com/item/1000007480470.html?scm_id=1007.14452.398466.0&scm-url=1007.14452.398466.0)
Motion | GT2 Pulley 20T | 4 |  | For X/Y Motors | $2.07 | $8.28 | $8.28 | $8.28 |  | Aliexpress | GT2 20Teeth 16 Teeth 20 Teeth Bore 5mm/8mm Timing Alumium Pulley Fit For GT2-6mm Open Timing Belt For 3D Printer - AliExpress (https://vi.aliexpress.com/item/32781681772.html?p)
Motion | GT2 Idler Pulley | 1 | 20TB5W10 | 5 x Smooth Idlers for XY need 2 | $5.69 | $5.69 | $5.69 | $5.69 |  | Aliexpress | 5/10P GT2 Idler Timing Pulley 16-Tooth 20-Teeth With 3MM or 5MM Bore With Bearings For 3D Printer Parts 2GT Timing Belt 6MM 10MM - AliExpress (https://vi.aliexpress.com/item/1005006489425002.html)
Motion | GT2 Idler Pulley with Teeth | 1 |  | 5 x Idlers with teeth for XY need 6 | $5.81 | $5.81 | $5.81 | $5.81 |  | Aliexpress | 5/10P GT2 Idler Timing Pulley 16-Tooth 20-Teeth With 3MM or 5MM Bore With Bearings For 3D Printer Parts 2GT Timing Belt 6MM 10MM - AliExpress (https://vi.aliexpress.com/item/1005006489425002.html)
Motion | GT2 9mm Belt | 1 | 4m | Closed Loop Belts | $32.79 | $32.79 | $32.79 | $32.79 |  | Aliexpress | Trianglelab Gates 2GT belt synchronous belt Timing belt Width 6mm 9mm length 2m 4m 6m wear GT2 resistant for Ender3 cr10 Anet - AliExpress (https://vi.aliexpress.com/item/1005007481359010.html)
Motion | NEMA17 Stepper | 2 | 42x42x48 | 17HE19-2004S1 X/Y Axis | $16.55 | $33.10 | $0.00 | $33.10 |  | StepperOnline | Nema 17 Bipolar 59Ncm(83.55oz.in) 2A 42x42x48mm 4 Wires w/ 1m Cable & Connector - 17HS19-2004S1 | StepperOnline (https://www.omc-stepperonline.com/nema-17-bipolar-59ncm-84oz-in-2a-42x48mm-4-wires-w-1m-cable-connector-17hs19-2004s1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)
Motion | T8x2 Leadscrew | 3 | 400mm | Z Axis Motion | $10.69 | $32.07 | $32.07 | $32.07 |  | Aliexpress | T8 Lead Screw With nut OD 8mm Lead 2mm Pitch 2mm 100mm 200mm 300mm 400mm 500mm Lead Screw With Brass Nut Reprap 3D Printer Parts - AliExpress 7 (https://vi.aliexpress.com/item/1005007457419235.html)
Motion | Brass T8 Nut | 0 |  | 4 x Leadscrew Nut | $5.59 | $0.00 | $0.00 | $0.00 |  | Included above | 1/2/4/10 PCS T8 LeadScrew 2mm Pitch 4 Start 8mm Helical Pitch Brass Nut for 3D Printer Z Axis T8x8 Tr8x8 Thread Screw Rod Nut - AliExpress (https://vi.aliexpress.com/item/1005008658088705.html)
Motion | Rigid Coupler 5x8mm | 3 |  | 5 x 8 Motor to Screw | $5.09 | $15.27 | $15.27 | $15.27 |  | Aliexpress | D20L25/30/35 3D Printer Part Lead Screw Coupler 1PC Rigid Coupling 8x10 6x8 5x8mm Motor Connector Motor Shaft Coupling - AliExpress (https://vi.aliexpress.com/item/1005006218903688.html)
Motion | NEMA17 Stepper | 1 | 42x42x39 | 3 x for Z Axis 17HE15-1504S | $22.41 | $22.41 | $0.00 | $22.41 |  | StepperOnline | 3pcs E Series Nema 17 Bipolar 42Ncm(59.49oz.in) 1.5A 42x42x38mm 4 Wires w/ 1m Cable & Connector - 3-17HE15-1504S | StepperOnline (https://www.omc-stepperonline.com/3-pcs-e-series-nema-17-bipolar-42ncm-59-49oz-in-1-5a-42x42x38mm-4-wires-w-1m-cable-connector-3-17he15-1504s)
Hotend | Rapido UHF | 1 |  | High Flow Hotend | $157.99 | $157.99 | $0.00 | $157.99 | E3d Ceramic | Aliexpress | Trianglelab NEW V2 Phaetus Rapido Hotend 2.0 HF 104NT PT1000 UHF High Speed High Effcient Heating Unit For VORON 3D PRINTER - AliExpress (https://vi.aliexpress.com/item/1005006870064580.html)
Motion | NEMA17 Stepper for Extruder | 1 | 42x42x39 | For Extruder 17HE15-1504S | $8.12 | $8.12 | $0.00 | $8.12 |  | StepperOnline | E Series Nema 17 Bipolar 42Ncm(59.49oz.in) 1.5A 42x42x38mm 4 Wires w/ 1m Cable & Connector - 17HE15-1504S | StepperOnline (https://www.omc-stepperonline.com/e-series-nema-17-bipolar-42ncm-59-49oz-in-1-5a-42x42x38mm-4-wires-w-1m-cable-connector-17he15-1504s)
Hotend | BMG Clone Extruder | 1 |  | Bowden Setup | $5.80 | $5.80 | $5.80 | $5.80 |  | Aliexpress | 3D Printer Upgraded Aluminum MK8 Extruder Drive Feed Kit for Ender 3/3 Pro/3 V2, Ender 5/5 Pro/5 Plus, CR-10/10S - AliExpress (https://vi.aliexpress.com/item/1005004923874649.html)
Hotend | PTFE Tubing | 1 | 500mm | Bowden Tube | $15.79 | $15.79 | $15.79 | $15.79 |  | Aliexpress | Creality 3d Capricorn Bowden Ptfe Tubing Xs Serie Blue 1m Tube Quick Fitting 1pcs Pneumatic Fitting Push 1.75mm Filament - 3d Printer Parts & Accessories - AliExpress (https://vi.aliexpress.com/item/1005004860520337.html)
Hotend | 5015 Blower Fan | 1 |  | Part Cooling | $11.89 | $11.89 | $11.89 | $11.89 |  | Aliexpress | Gdstime DC 5V 12V 24V 50x50x15mm Dual Ball Cooler 2Pin USB Radial Fan 5015 Turbo Blower 5cm 50mm Radiator for 3D Printer Cooling - AliExpress (https://vi.aliexpress.com/item/1005007606844263.html)
Hotend | 40mm Fan | 1 |  | Hotend Cooling | $5.12 | $5.12 | $5.12 | $5.12 |  | Aliexpress | 4010 12025 8010 30mm dc 5V 12V 24V Cooling Fan Brushless Motor Case Quiet 40MM 50MM 60MM 70MM 80MM 90MM 120MM for 3D print 2PIN - AliExpress (https://vi.aliexpress.com/item/1005006306536871.html)
Electronics | BTT Manta M8P mainboard includes CB1 + 8 x TMC2209 | 1 |  | Controller | $130.00 | $130.00 | $130.00 | $130.00 |  | Aliexpress | BIGTREETECH Manta M8P V2.0 Motherboard STM32H723ZE 32bit for Klipper Raspberry Pi For Voron V0 Ender 3 3D Printer Control Board - AliExpress 7 (https://vi.aliexpress.com/item/1005006344900911.html)
Electronics | 24V PSU 600W | 1 |  | Power Supply | $80.19 | $80.19 | $80.19 | $80.19 |  | Aliexpress | Original Mean Well RS-15/25 LRS-35/50/100/150/200/350/450/600 Series Meanwell 3.3V 5V 12V 15V 24V 36V 48V Switching Power Supply - AliExpress (https://vi.aliexpress.com/item/1005006092154615.html)
Electronics | 350x350 Bed | 1 |  | Aluminium | $144.99 | $144.99 | $144.99 | $144.99 |  | Aliexpress | Voron 0/0.1/0.2/2.4/Trident 6061 Aluminum Alloy Plate 120*120*6mm 350*350*8mm for Voron 3D Printer Accessories Printing Platform - AliExpress (https://vi.aliexpress.com/item/1005004428776917.html)
Electronics | 350x350 Heated Bed | 1 |  | Bed Heater 340 340 | $142.45 | $142.45 | $142.45 | $142.45 |  | Fermio | V1/V2/VT Silicone Bed Heater Mat by Fermio Labs - 340x340mm - Unique Prints (https://uniqueprints.shop/shop/buildplate/v1-v2-vt-silicone-bed-heater-mat-by-fermio-labs-340x340mm/)
Electronics | SSR | 1 |  | For AC Bed Heater (if used) | $19.69 | $19.69 | $19.69 | $19.69 |  | Aliexpress | New Authentic Original OMRON Solid State Relay G3NB-205B-1 210B-1 220B-1 225B-1 240B-1 275B-1 5A (https://vi.aliexpress.com/item/1005005225476958.html)
Electronics | Thermistor 100K | 1 |  | Bed/Hotend Sensing |  | $0.00 | $0.00 | $0.00 |  | Included above
Electronics | Wiring Kit | 1 |  | Power & Signal Wiring | $100.00 | $100.00 | $100.00 | $100.00 |  | Various
Misc | Build Surface | 1 | 350x350mm | PEI/Glass/Magnetic Plate | $46.77 | $46.77 | $46.77 | $46.77 |  | Aliexpress | Magnetic PEI Powder Sheet 235/250/310/350/220mm Double Sided Spring Steel Sheet Textured For Ender 3 CR10 P1P SW-X1 Build Plate - AliExpress 7 (https://vi.aliexpress.com/item/1005005569535639.html)
Misc | Cable Chains | 2 |  | X and Z Axes | $20.00 | $40.00 | $0.00 | $40.00 |  | Aliexpress
Misc | Silicone Spacers | 1 |  | Bed Mounting | $3.79 | $3.79 | $3.79 | $3.79 |  | Aliexpress | 1-6set Hot Bed Leveling Column Silicone Solid Spacer Platform Leveler For CR10/ CR10S CR-X Ende-3 ELEGOO Kobra 3D Printer Parts - AliExpress 7 (https://vi.aliexpress.com/item/1005007045883147.html?scm_id=1007.40196.439370.0&scm-url=1007.40196.439370.0)
Misc | Printed Parts | 1 |  | Brackets, Mounts, Carriages |  | $0.00 | $0.00
Misc | Enclosure Panels | 1 |  | 6 mm Acrylic 6 sheets 600x600 | $200.00 | $200.00 | $200.00
 |  |  |  |  |  |  | $1119.73 | $1391.75

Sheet: STL Links
Category | Component | STL Name | STL URL | Notes
Frame | XY Joint Bracket | XY_Joint_Bracket_v1.stl | https://example.com/xy_joint_bracket_v1 | Print in PETG, 4 walls
Motion | Belt Tensioner | Belt_Tensioner_v2.stl | https://example.com/belt_tensioner_v2 | Print in ABS for strength
Electronics | SSR Mount | SSR_Mount_v1.stl | https://example.com/ssr_mount_v1 | Print in PLA, optional

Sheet: Cut List
Frame
Component | Size | Notes | Lrngth | Quantity | MMs | Cut from Code |  |  |  |  |  |  |  |  |  |  | Notes
1 | 20x40 V-slot | Base/Top Front & Back | 550 | 4 | 2200
2 | 20x40 V-slot | Verticals | 500 | 4 | 2000
3 | 20x40 V-slot | Base Sides | 460 | 2 | 920 |  | Looks like I needed 4
4 | 20x40 V-slot | Y Axis | 460 | 2 | 920
5 | 20x20 V-slot | Mid Upper Rear | 470 | 1 | 470
6 | 20x20 V-slot | Top Sides | 460 | 2 | 920
7 | 20x20 V-slot | X Axis | 430 | 1 | 430
8 | 20x20 V-slot | Bed Support Beam | 427 | 1 | 427
9 | 20x20 V-slot | Bed Support Beam | 365 | 1 | 365
10 | 20x20 V-slot | Z Axis Motion | 400 | 3 | 1200
 |  |  |  | 21
Stock
 |  |  |  |  |  |  | Cut Component from Stock
Code | Size | Length (mm) | Qty | MMs | Left Over | Colour | 1 | 2 | 3 | 4 | 5 | 6 | 7 | 8 | 9
A | 20x40 V-slot | 1500 | 2 | 3000 | 430 | Silver | 3 | 2
B | 20x20 V-slot | 920 | 1 | 920 | 0 | Silver |  |  |  | 2
C | 20x20 V-slot | 1000 | 1 | 1000 | 80 | Silver |  |  |  | 2
D | 20x20 V-slot | 1360 | 2 | 2720 | 228 | Silver |  |  |  |  | 1 |  | 1 | 1 | 3
E | 20x20 V-slot | 1500 | 2 | 3000 | 540 | Black |  |  | 1 |  |  | 4
F | 20x40 V-slot | 280 | 6 | 1680 | 1680 | Silver
G | 20x20 V-slot | 320 | 1 | 320 | 320 | Silver
H | 20x20 V-slot | 250 | 4 | 1000 | 1000 | Silver
 |  |  |  |  |  | Count | 3 | 2 | 1 | 4 | 1 | 4 | 1 | 1 | 3 | 20
 |  |  |  |  |  | Length | 550 | 460 | 460 | 460 | 500 | 500 | 427 | 365 | 400
 |  |  |  |  |  | Cut Total | 1650 | 920 | 460 | 1840 | 500 | 2000 | 427 | 365 | 1200
 |  |  |  |  |  | Required | 2200 | 920 | 920 | 920 | 2000 | 2000 | 427 | 365 | 1200

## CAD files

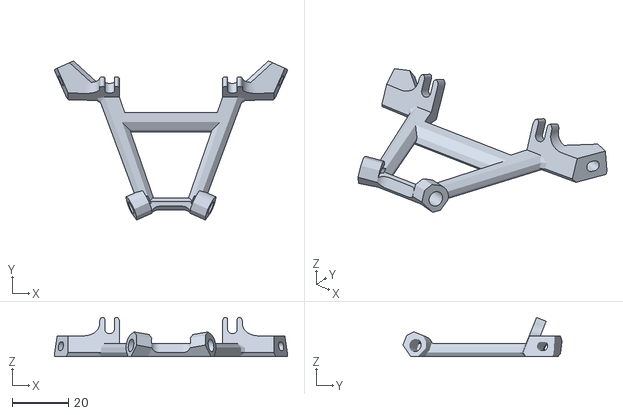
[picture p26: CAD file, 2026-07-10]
cad/Toolhead/Mantis Dual 5015 Direct Drive/STLs/Duct_Brace/Full_Brace/Dragon/Duct_Brace_Dragon_Full_v1.2_Open_mount.stl
83.2 x 56.8 x 14.0

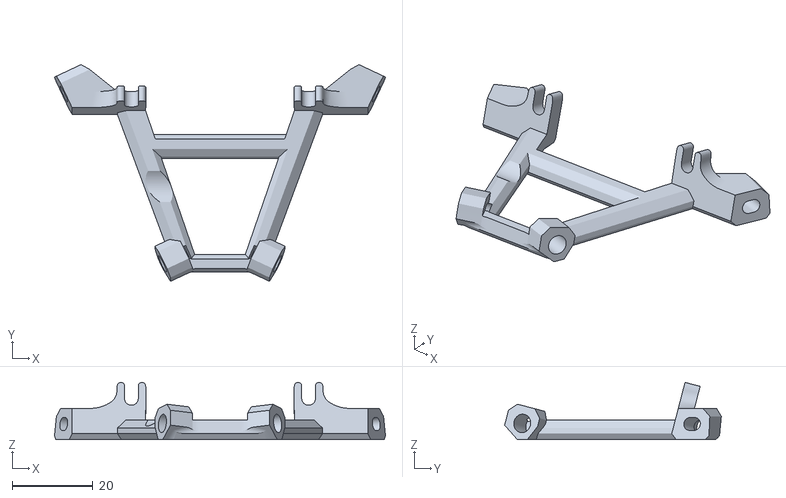
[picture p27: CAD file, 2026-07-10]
cad/Toolhead/Mantis Dual 5015 Direct Drive/STLs/Duct_Brace/Full_Brace/Rapido_Crazy_Volcano/Duct_Brace_Rapido_Crazy_Volcano_Full_v1.2_Open_Mount.stl
81.9 x 53.6 x 14.2

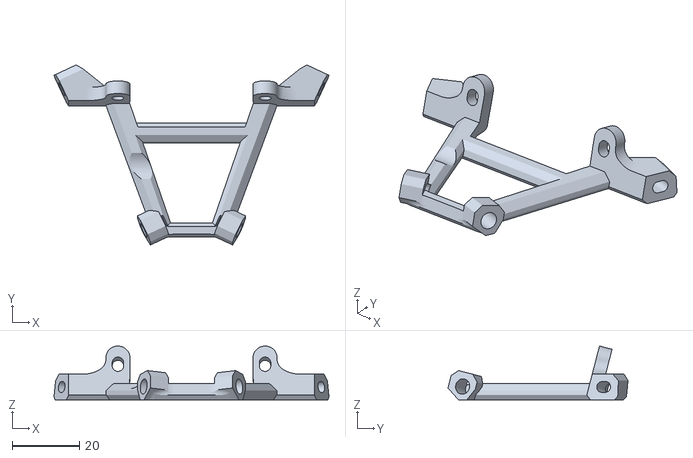
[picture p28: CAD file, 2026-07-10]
cad/Toolhead/Mantis Dual 5015 Direct Drive/STLs/Duct_Brace/Full_Brace/Rapido_Crazy_Volcano/Duct_Brace_Rapido_Crazy_Volcano_Full_v1.2_Closed_Mount.stl
81.9 x 53.6 x 16.1

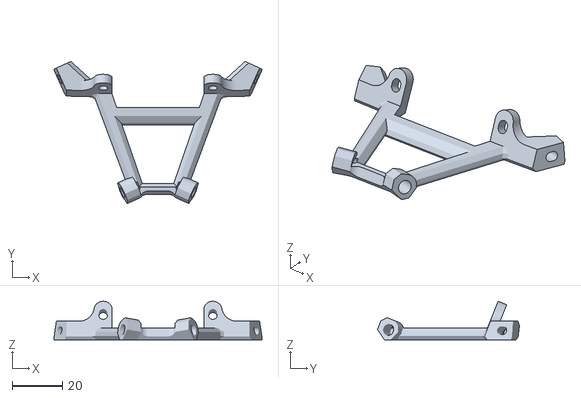
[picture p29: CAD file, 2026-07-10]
cad/Toolhead/Mantis Dual 5015 Direct Drive/STLs/Duct_Brace/Full_Brace/Dragon/Duct_Brace_Dragon_Full_v1.2_Closed_mount.stl
83.2 x 56.8 x 15.4

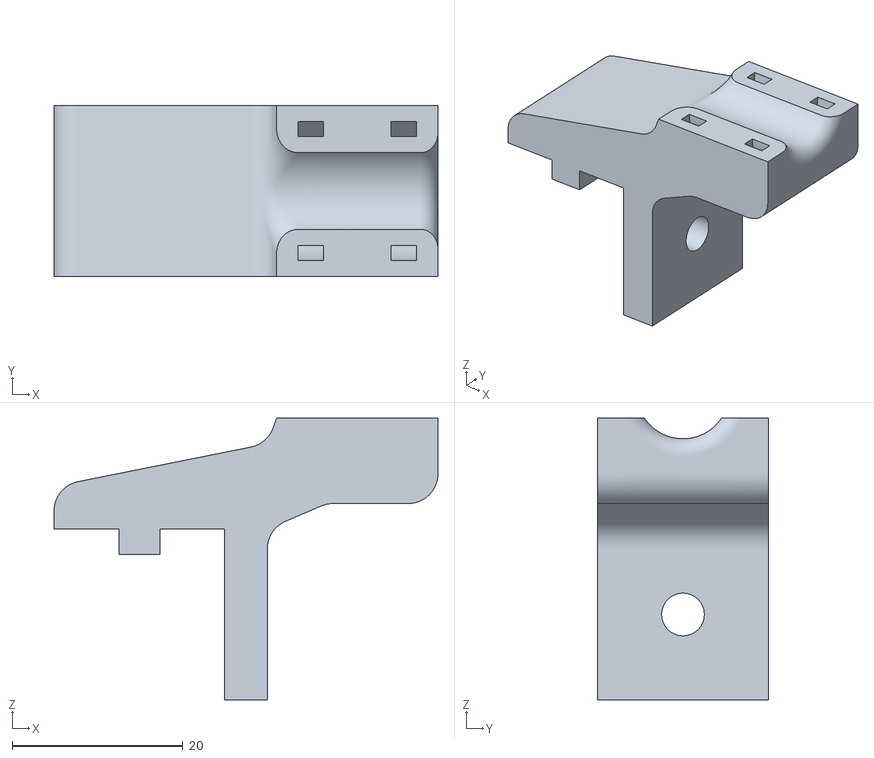
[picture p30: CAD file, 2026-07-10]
cad/Heated Bed/hevo_strain_relief_v5.stl
45.0 x 20.0 x 33.0

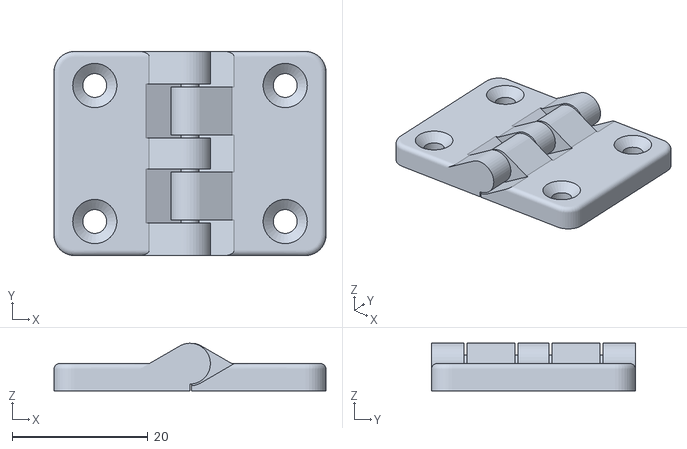
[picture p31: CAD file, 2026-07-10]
cad/STLs/Door Hinges/files/Hinge_40x30_4mm_printinplace.stl
40.0 x 30.0 x 7.00

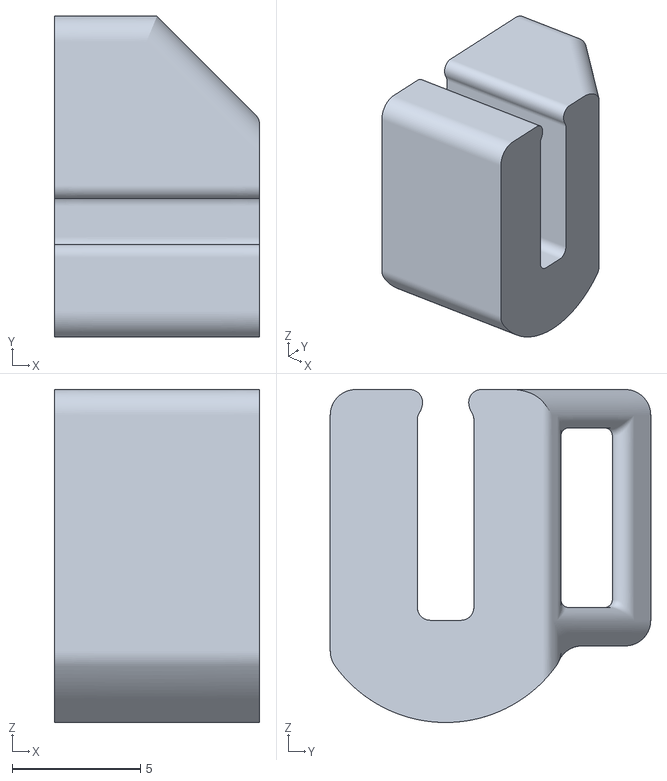
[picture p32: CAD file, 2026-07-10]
cad/STLs/GT2 Clamps/Clamp_2.stl
8.00 x 12.5 x 13.0

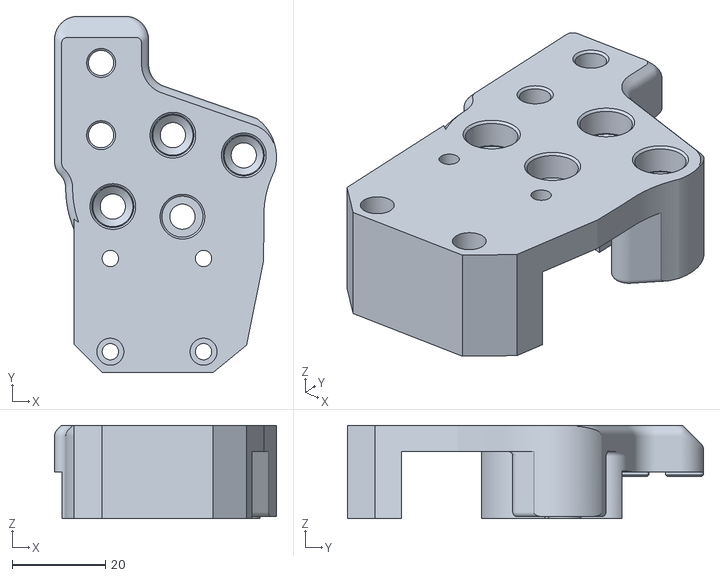
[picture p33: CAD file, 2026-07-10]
cad/STLs/SimpleCore Remix RH XY mgn12h - XY Joint - Left 9mm TOP.stl
47.6 x 76.5 x 20.0

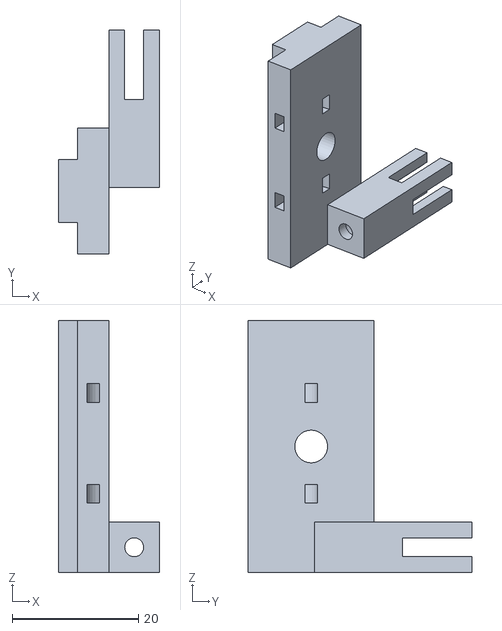
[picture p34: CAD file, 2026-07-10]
cad/Thermister Housing/STL/SkipCore Thermistor Housing Mk1a.stl
16.0 x 35.5 x 40.0

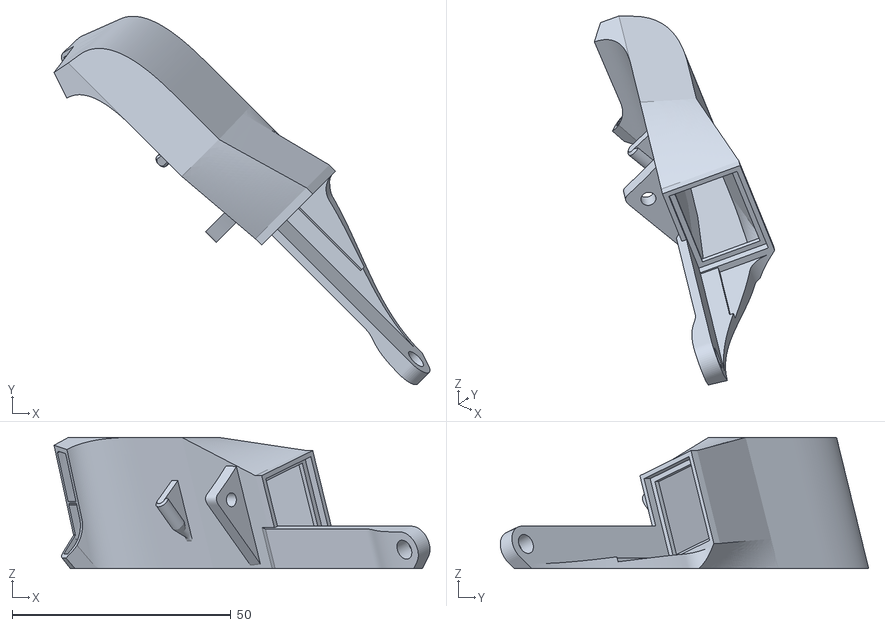
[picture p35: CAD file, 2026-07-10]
cad/Toolhead/Kingroon Mantis/duct_rapido_hf_v003b_right.stl
86.0 x 84.3 x 30.0

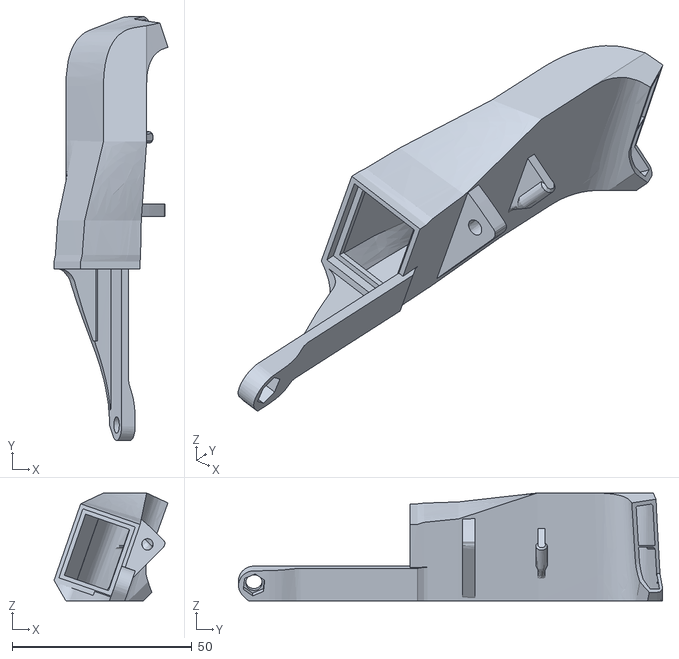
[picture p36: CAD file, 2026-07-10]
cad/Toolhead/Mantis Dual 5015 Bowden/mantisdual5015_tze3_ender3_cr10_mod_duct_left.stl
31.6 x 117.8 x 30.0

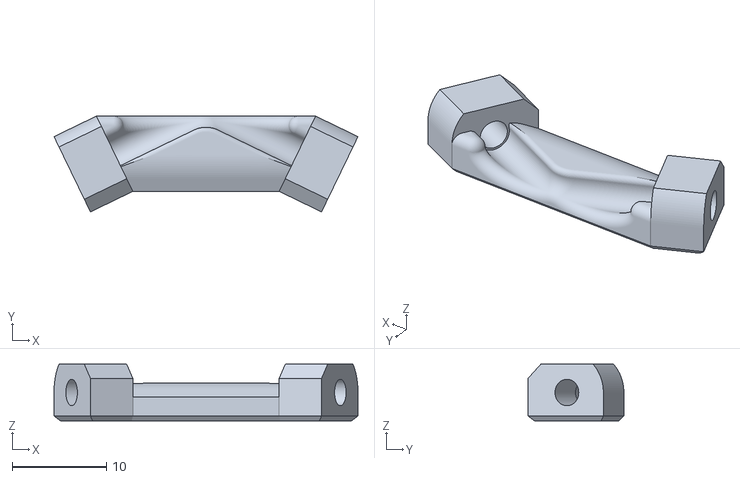
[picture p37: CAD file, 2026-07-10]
cad/Toolhead/Mantis Dual 5015 Direct Drive/STLs/Duct_Brace/Duct_Brace_Simple_v1.0.stl
32.3 x 10.2 x 6.00

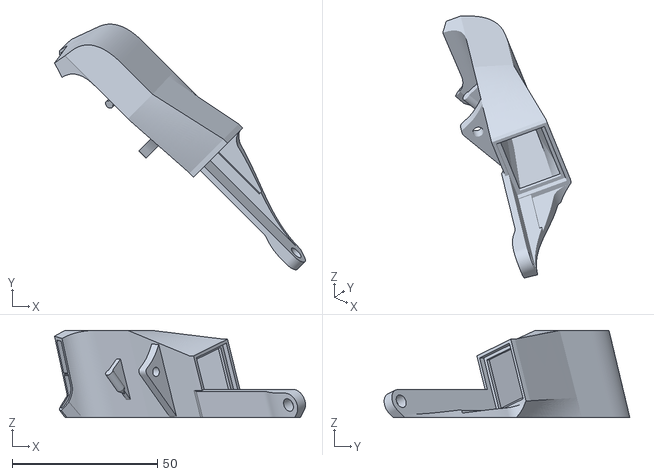
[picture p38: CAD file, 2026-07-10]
cad/Toolhead/Mantis Dual 5015 Direct Drive/STLs/Ducts/1.8/Duct_v1.037_Right_+2mm.stl
86.4 x 84.6 x 30.0

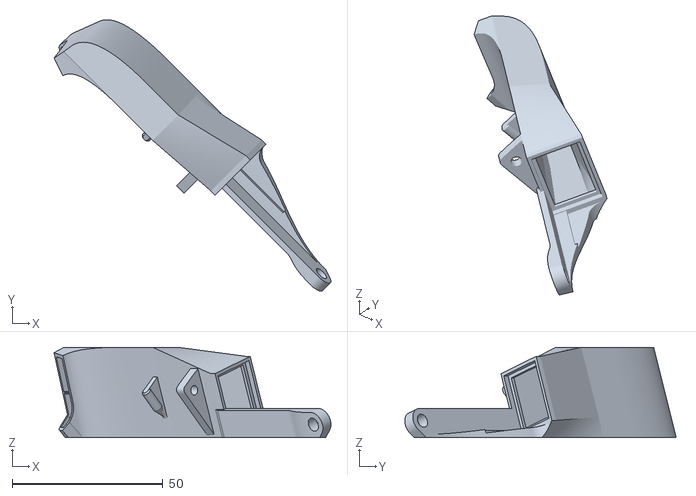
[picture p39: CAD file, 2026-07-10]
cad/Toolhead/Mantis Dual 5015 Direct Drive/STLs/Ducts/2.4/duct_rapido_UHF_v0.03b_right.stl
92.0 x 90.2 x 30.0

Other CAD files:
cad/Toolhead/Mantis Dual 5015 Direct Drive/STLs/Hotend_Mount_Dragon_v1.040.stl
cad/Toolhead/Mantis Dual 5015 Direct Drive/STLs/Magprobe/Bed_Extrusion_Mount/Magprobe_Dock_Mount_v1.0.stl
cad/Toolhead/Mantis Dual 5015 Direct Drive/STLs/Magprobe/Gantry_Mount/Magprobe_Gantry_Dock_Arm_v1.5_double_magnet.stl
cad/Blender/SimpleCore CoreXY Motor mounts.blend
cad/Blender/SimpleCore Remix LH XY mgn12h - XY Joint - Left BOTTOM.blend
cad/Blender/SimpleCore Remix LH XY mgn12h - XY Joint - Left TOP.blend
cad/Blender/SimpleCore Remix LH XY mgn12h - XY Joint - Right TOP.blend
cad/Blender/SimpleCore Remix Rear Idlers 9mm.blend
cad/Blender/SimpleCore Remix 9mm Rear Idler.blend
cad/Blender/SimpleCore Remix z axis motor mount.blend
cad/Blender/Z Axis Leadscrew Upper support.blend
cad/Blender/Z Axis Leadscrew nut to gantry bracket.blend
cad/Blender/Z Gantry Bracket with Leadscrew nut mount Mk 4.blend
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

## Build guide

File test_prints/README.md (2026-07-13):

# SkipCore350 Test Prints

This folder contains small commissioning prints used before serious tuning.

## 100 x 100 first-layer squaring frame

Files:

- `SkipCore350_100x100_1layer_5mm_frame.stl` — slicer-friendly 100 x 100 x 0.2 mm frame.
- `SkipCore350_100x100_slow_PLA_rear_right_zero.gcode` — direct Klipper G-code for the current SkipCore coordinate model.

Use the STL through Orca/SuperSlicer for normal use. Use the direct G-code only when the machine coordinate setup has been confirmed:

```text
rear-right = X0 Y0
printable area = negative X/Y
bed size = 330 x 330 mm
```

The direct G-code prints centred around `X-165 Y-165`, with movement around `X -215..-115` and `Y -215..-115`.

## Measurement targets

```text
Outer X side: 100.00 mm
Outer Y side: 100.00 mm
Ideal diagonal: 141.42 mm
```

Measure:

```text
front edge
rear edge
left edge
right edge
diagonal 1
diagonal 2
```

If both sides are close but diagonals differ, investigate XY skew/squareness.

## Caution

Watch the first direct G-code run carefully. It includes homing, bed/nozzle heat, and a short prime line. It assumes the rear-right-zero/negative-coordinate setup documented in `COMMISSIONING.md`.

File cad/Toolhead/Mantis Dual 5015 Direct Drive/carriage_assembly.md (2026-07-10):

<table width=100%>
<TR>
<TD align="center"><B>Link</TD><TD align="center"><B>Description</TD></TR>
<TR><TD align="center"><a href="readme.md">Readme</A></TD><TD align="center">Mantis Description and Updates</TD></TR>
<TR><TD align="center"><a href="bom_acknowledgements.md">BOM and Acknowledgements</A></TD><TD align="center">BOM, links to other repositories, acknowledgements</TD></TR>
<TR><TD align="center"><a href="print_orientation.md">Print Orientation</A></TD><TD align="center">Printing the parts</TD></TR>
<TR><TD align="center"><a href="carriage_assembly.md">Carriage Assembly</A></TD><TD align="center">Building the MGN9, MGN12 Carriage, Hotend Mounts</TD></TR>
<TR><TD align="center"><a href="magprobe.md">Magprobe Assembly</A></TD><TD align="center">Assembly of Mag Probe</TD></TR>
<TR><TD align="center"><a href="firmware_slicer_settings.md">Firmware and Slicer Settings</A></TD><TD align="center">Firmware and Slicer Settings</TD></TR>
<TR><TD align="center"><a href="1.8_trident.md">Voron 1.8 and Trident</A></TD><TD align="center">Notes on Voron 1.8 and Trident</TD></TR>
<TR><TD align="center"><a href="final_assembly.md">Final Assembly</A></TD><TD align="center">Notes and Pictures of final assembly</TD></TR>
<TR><TD align="center"><a href="https://github.com/mandryd/MantisUsermods/tree/main/Usermods">Usermods</A></TD><TD align="center">Mods by Mantis Users (note: separate repository)</TD></TR>
<TR><TD align="center"><a href="https://github.com/mandryd/VoronUsers/tree/master/printer_mods/Long/Mantis_Dual_5015">Long's Mantis Repository</A></TD><TD align="center">Long's Repository for Mantis.  Updates and newest stuff will be found here</TD></TR>
</table>

Carriage and Hotend Mount Assembly
============
**Carriage Assembly:**
- Magnets:
  - <a href="https://youtu.be/G4MdrRXfb1M">Quick video on soldering magnets</A>
  - Sand the side of 2 m6x3 magnets. Place a magnet on a bigger stack of magnets then solder a piece of wire to the side as shown.
  - If you don’t have the magnet on the bigger stack, your magnet will lose some of its magnetic strength. I haven’t tested, but I think it’s probably ok because of the double stack with an unsoldered magnet (and the magnet being soldering is the magnet on the inside).
  - Put superglue into the magnet holes.
  - Place the second magnet on the soldered magnet, and then press the two magnets into the hole so the unsoldered magnet is out. The magnets should sit “proud” of the carriage.  
  - I use a flat surface to press the magnets in and then lap them so they mate well with the mag probe.
  - Note, previously, attaching the magnets by pinching the wires was thought to be ok.  After further testing, the "wire pinch" method of attaching the wires to the magnets is no longer recommended due to failures of the connection over time.
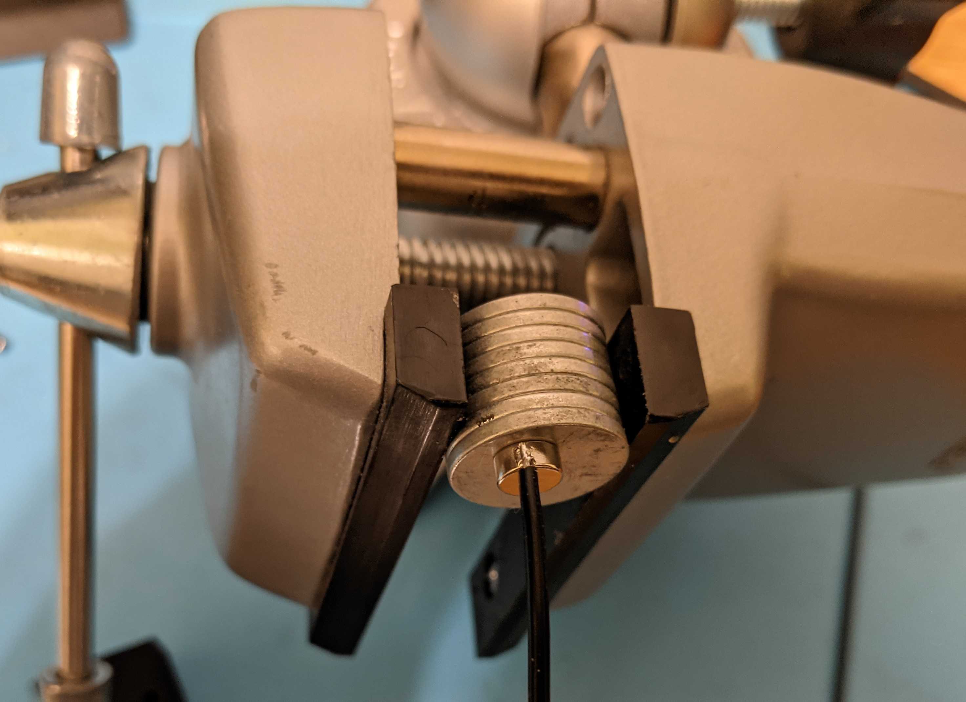
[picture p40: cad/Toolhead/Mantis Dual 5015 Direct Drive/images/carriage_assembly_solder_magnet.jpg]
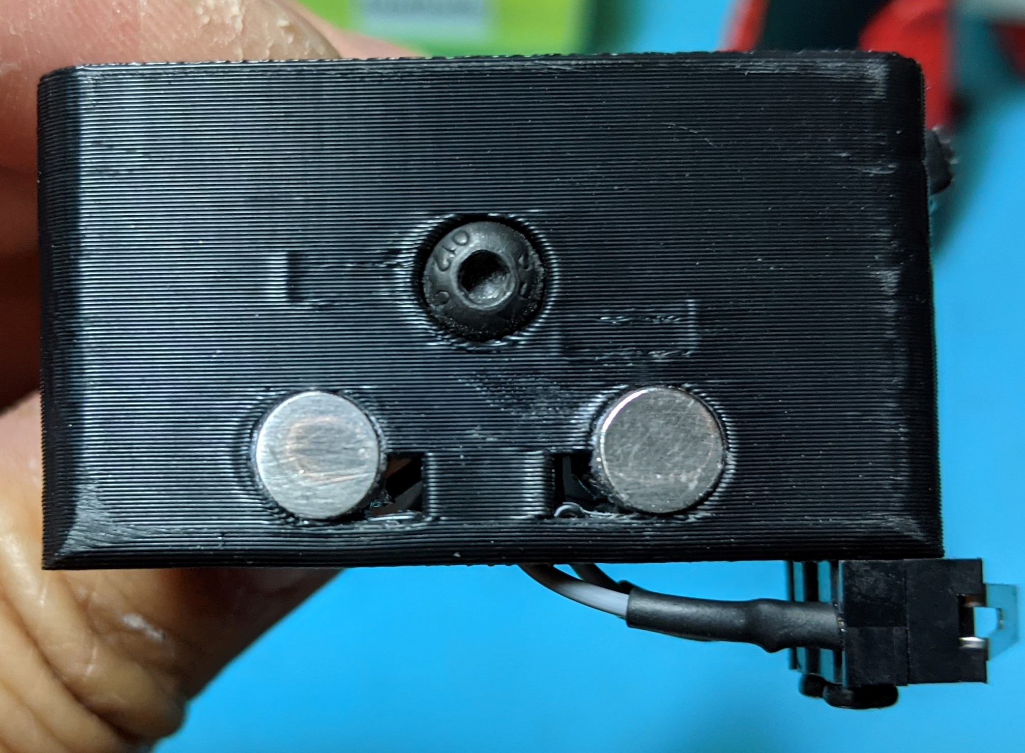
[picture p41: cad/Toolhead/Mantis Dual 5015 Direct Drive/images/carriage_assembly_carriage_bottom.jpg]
  - 
- Misc Notes
  - Adjust the tilt of your magprobe by screwing in and out the m3x6 button head screw on the bottom of the carriage.
  - Do not forget to put superglue into the holes in the carriage prior to putting in the magnets.
  - Hole on left side of carriage is for ADXL mounting. (Thanks @Koonweee)
- Heatsets
  - As shown on front and top. There will be an extra hole on top/right. This extra hole is currently unused and is present to allow for mods.  
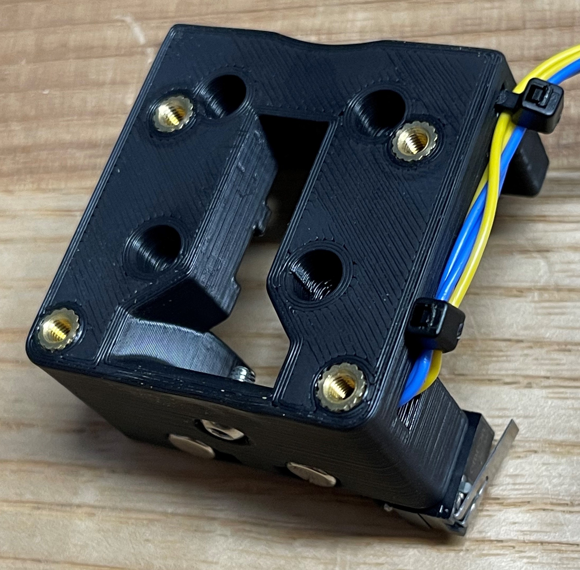
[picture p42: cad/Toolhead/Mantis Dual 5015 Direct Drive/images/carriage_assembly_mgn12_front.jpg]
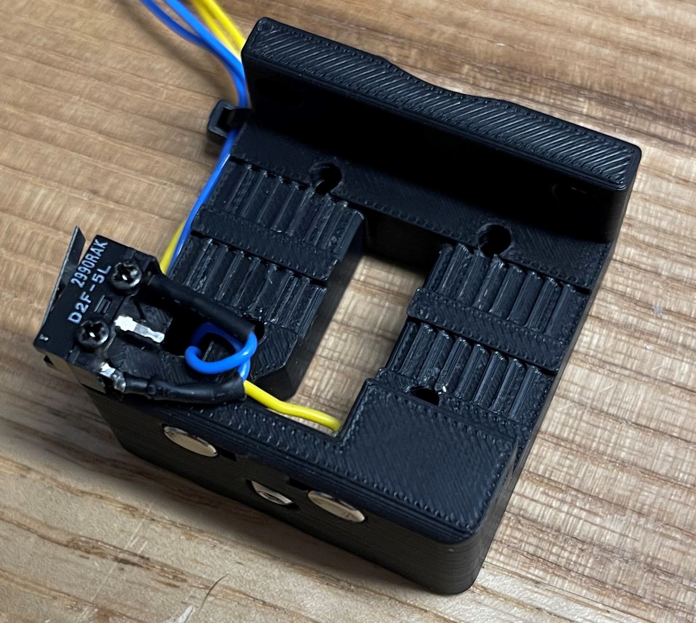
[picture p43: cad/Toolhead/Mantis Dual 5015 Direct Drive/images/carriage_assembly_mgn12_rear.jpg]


**MGN9 Carriage Notes:**
- Notes
  - Mounting Mantis with a single MGN9 carriage is possible. I am currently testing this with a Robotdigg 440 SUS MGN9 rail. So far, I am not noticing any loss in quality after switching from MGN12 using the same slicer profile. However, your results may vary depending on the quality of your linear rail.
  - For a Voron 300, MGN12 is 278g. MGN9 is 157g, which will help during Y-axis moves. 
  - Is it better than mgn12? I haven’t tested long enough to know. I will eventually ramp speeds and see.
- Printing and Assembly
  - The MGN9 carriage is tricky to get to print perfectly due to some steep overhangs. However, if these overhangs do not come out well, it should not affect the functionality of the part. The overhangs are part of the belt path, so as long as the belt goes through from the back to the front, you’ll be ok.
  - The belts are clamped using makerbeam T-nuts (see the V0.1 BOM for these)
  - You can use up to m3x8mm or m3x10mm SHCS or BHCS with the T-nuts.
  - m3x10mm nuts will make threading the belts easier.
  - I used openbuild T-nuts (because I had them around) and dremeled them narrower
  - m3x8mm bolts to attach carriage to MGN9.
  - Make sure the carriage is straight while tightening. If your carriage is tilted, using Auto-Z calibration will give inconsistent results. If you need to adjust the tile, note that you can loosen the carriage bolts without loosening the belts
<table>
  <TR>
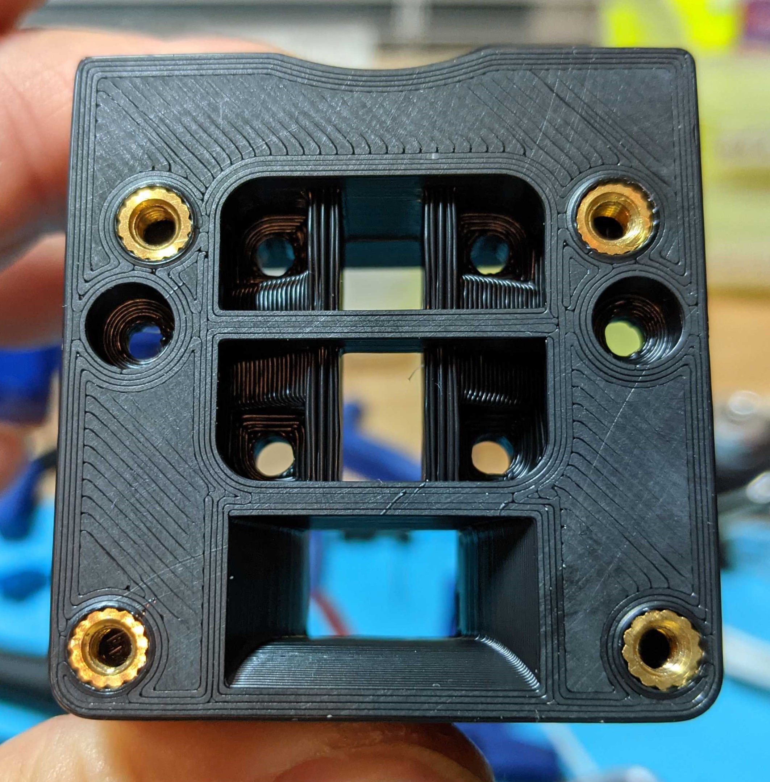
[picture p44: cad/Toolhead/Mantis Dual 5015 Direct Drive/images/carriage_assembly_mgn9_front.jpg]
    <TD align="CENTER" width=50%></TD>
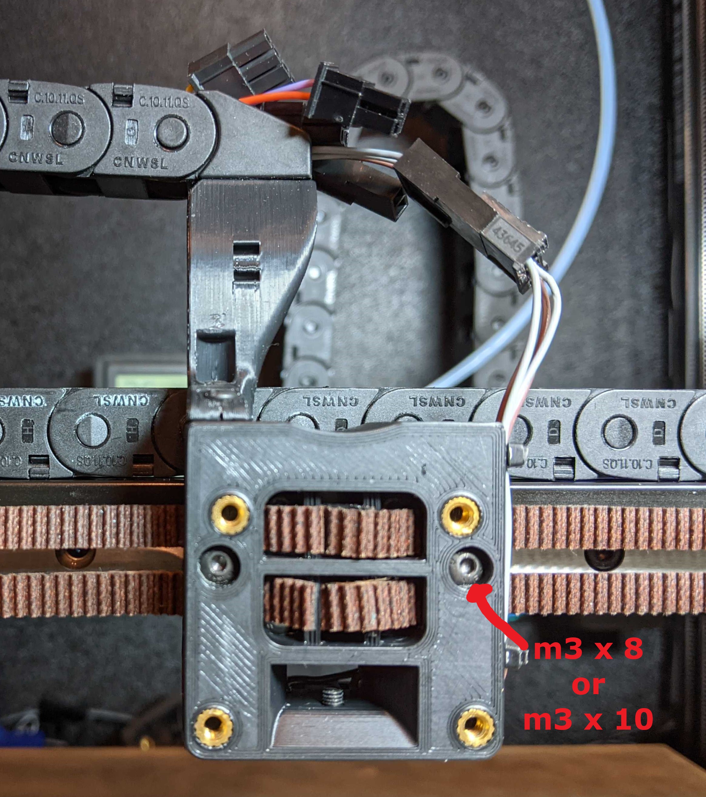
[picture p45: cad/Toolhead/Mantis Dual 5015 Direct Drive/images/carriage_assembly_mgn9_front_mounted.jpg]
    <TD align="CENTER" width=50%></TD>
  </TR>
<TR>
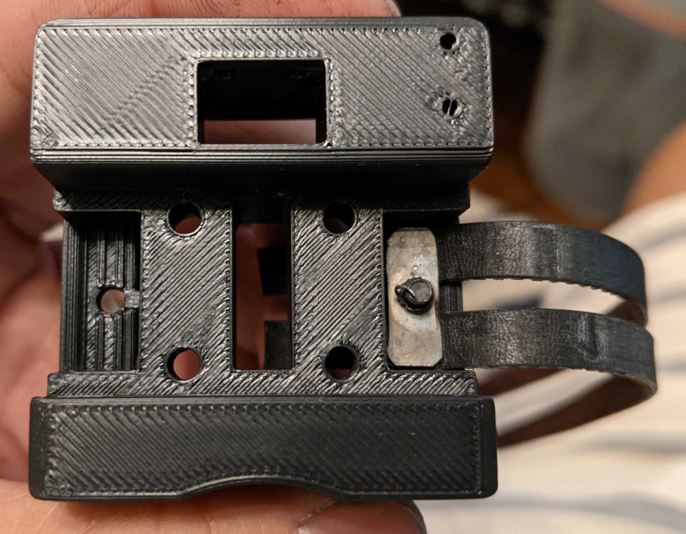
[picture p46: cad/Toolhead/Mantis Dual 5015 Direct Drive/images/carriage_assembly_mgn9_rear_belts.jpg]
    <TD align="CENTER" width=50%><BR>I'm using a filed down openbuild T-Nut here.  There are other mods to use t-nuts and hex nuts in <a href="https://github.com/mandryd/MantisUsermods/tree/main/Usermods">usermods.</a></TD>
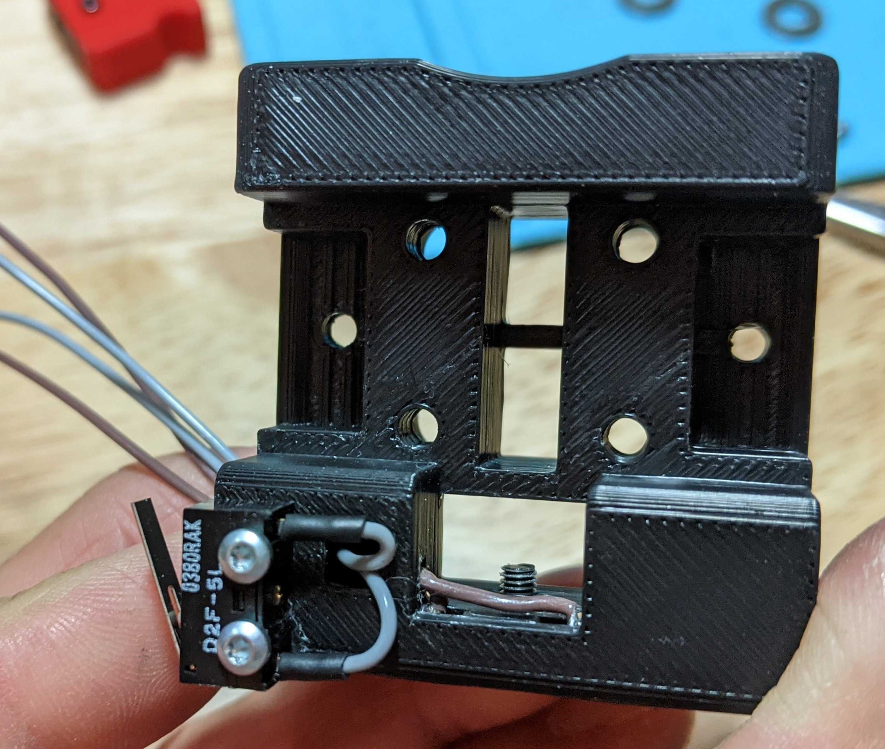
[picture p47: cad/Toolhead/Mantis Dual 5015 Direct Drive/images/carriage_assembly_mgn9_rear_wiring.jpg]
    <TD align="CENTER" width=50%></TD>
</TR>
</table>

**Hotend Mount Assembly:**
- Heatsets and screws
  - Install heat sets into the obvious places.  
  - 3010 fan uses screws directly into plastic.

<table>
  <TR>
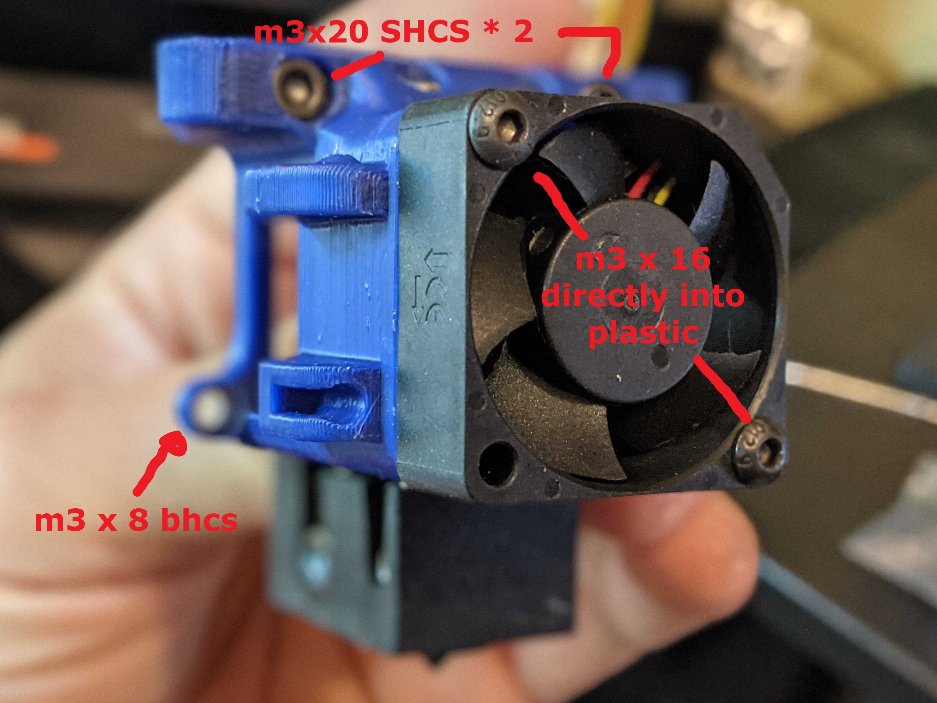
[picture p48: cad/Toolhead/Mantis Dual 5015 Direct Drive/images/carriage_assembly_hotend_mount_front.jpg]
    <TD align="CENTER" width=50%><BR><B>Dragon</B><BR>Heater cartridge is pointed to the back (opposite of afterburner/stealthburner)</TD>
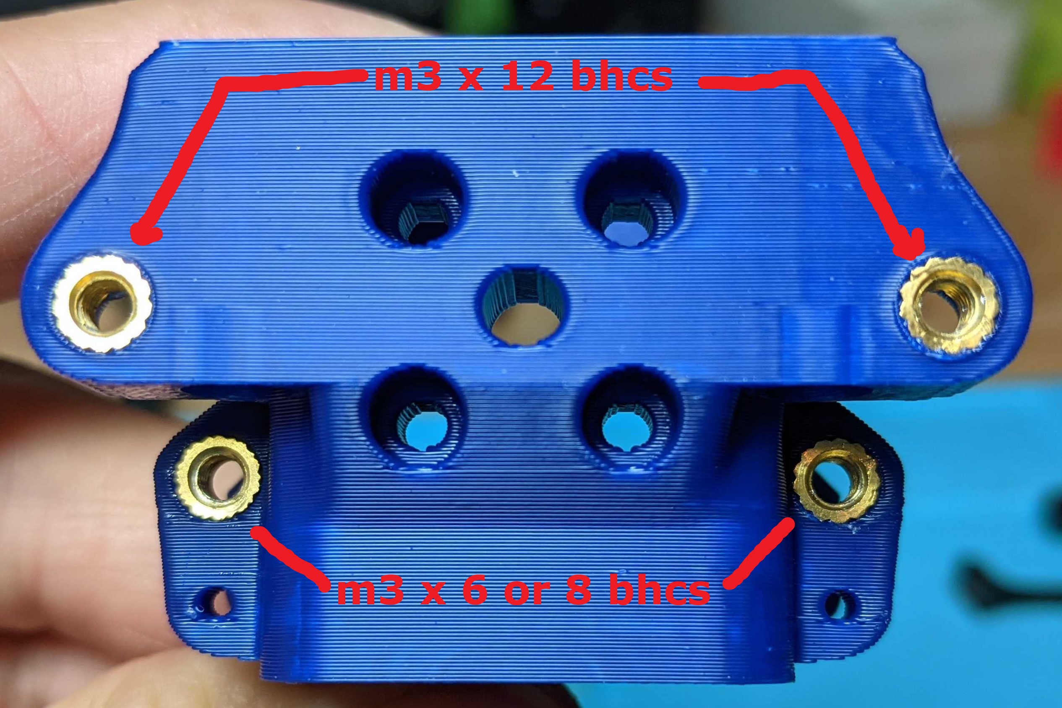
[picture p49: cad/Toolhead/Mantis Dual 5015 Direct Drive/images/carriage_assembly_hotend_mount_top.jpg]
    <TD align="CENTER" width=50%></TD>
  </TR>
<TR>
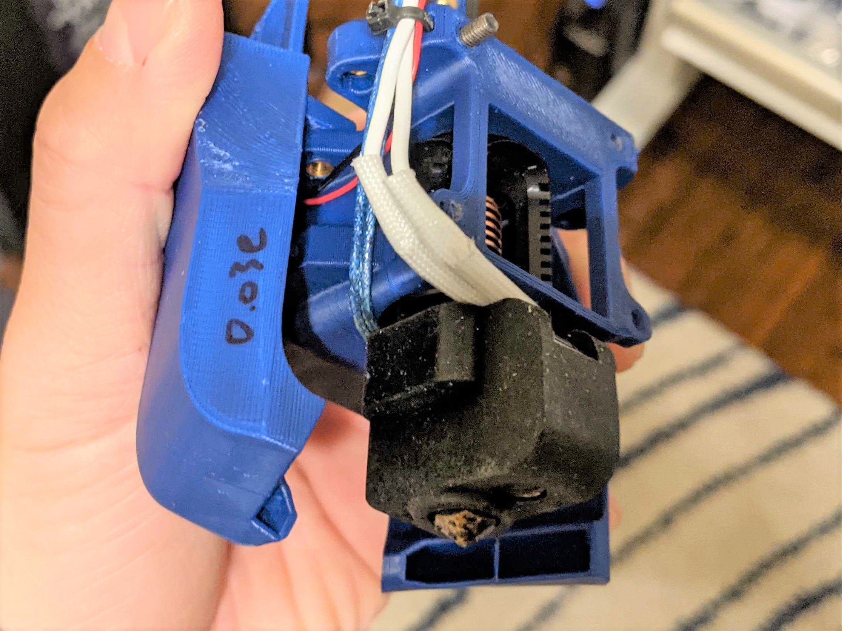
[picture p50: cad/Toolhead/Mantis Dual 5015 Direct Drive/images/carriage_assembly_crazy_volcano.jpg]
  <TD align="CENTER" width=50%><BR><B>Crazy Volcano</B><BR>Note Heater block orientation and wire pathing.</TD>
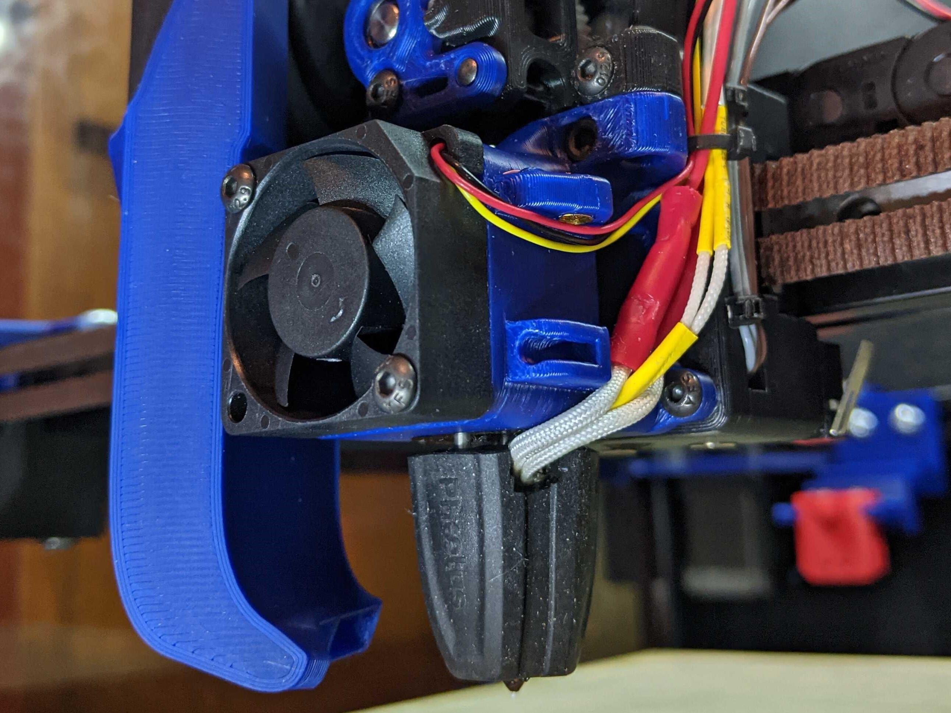
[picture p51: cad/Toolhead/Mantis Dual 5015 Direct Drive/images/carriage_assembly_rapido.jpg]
  <TD align="CENTER" width=50%><BR><B>Rapido</B><BR>Print the hotend mount (Hotend_Mount_Rapido_v.03 or Hotend_Mount_Rapido_v.03_Rotated120Degrees) that has the Phaetus logo on the sock facing directly forward.  <BR>Wires should come out right/forward</TD>
</TR>
</TABLE>
<Table>
<TR>
  <TD colspan=3 width=100%>Hotend mount (Hotend_Mount_Dragon_v1.040_sherpa_brace.stl) for dragon/dragon with crazy volcano that accepts <a href="https://github.com/Annex-Engineering/Annex-Engineering_User_Mods/tree/main/Extruders/Sherpa_Mini/Extruder_Mods/Long-housing_front_angled_front_brace">modified Sherpa mini housing_front</a>, which triangulates the extruder mounting and adds some stability.</TD>
</TR>  
<TR>
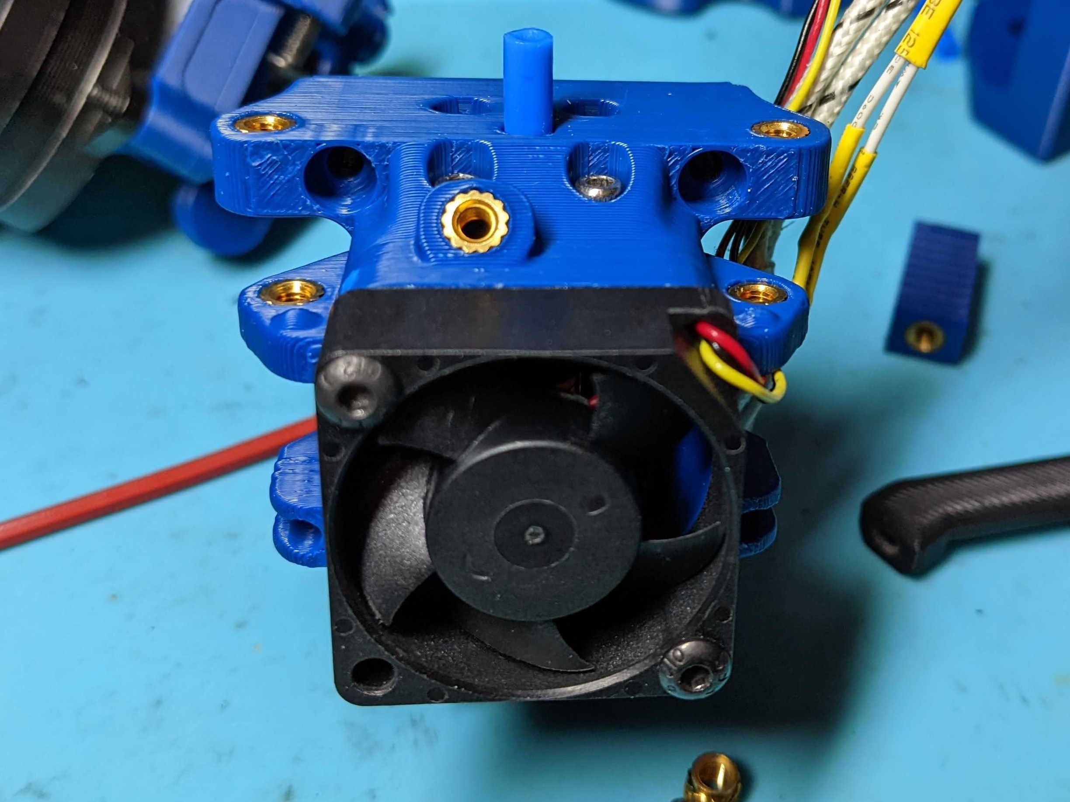
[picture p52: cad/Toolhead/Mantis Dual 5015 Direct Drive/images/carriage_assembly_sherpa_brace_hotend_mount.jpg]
  <TD align="CENTER" width=33%></TD>
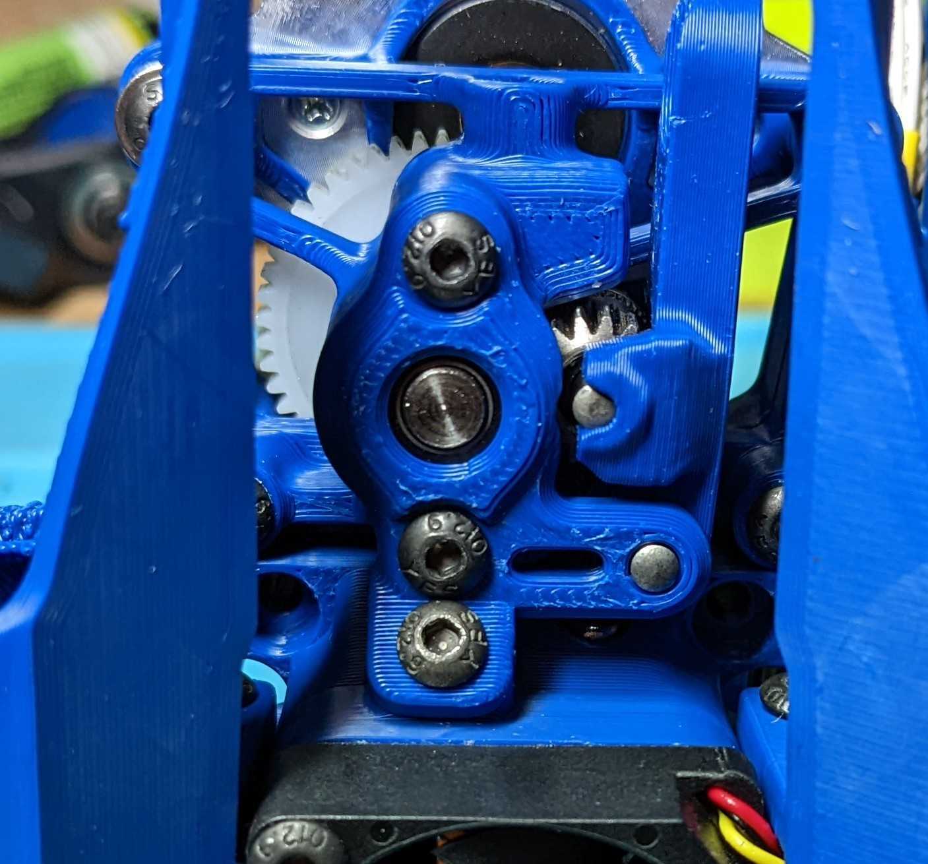
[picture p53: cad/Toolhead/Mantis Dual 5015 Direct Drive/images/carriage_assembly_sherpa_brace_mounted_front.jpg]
  <TD align="CENTER" width=33%></TD>
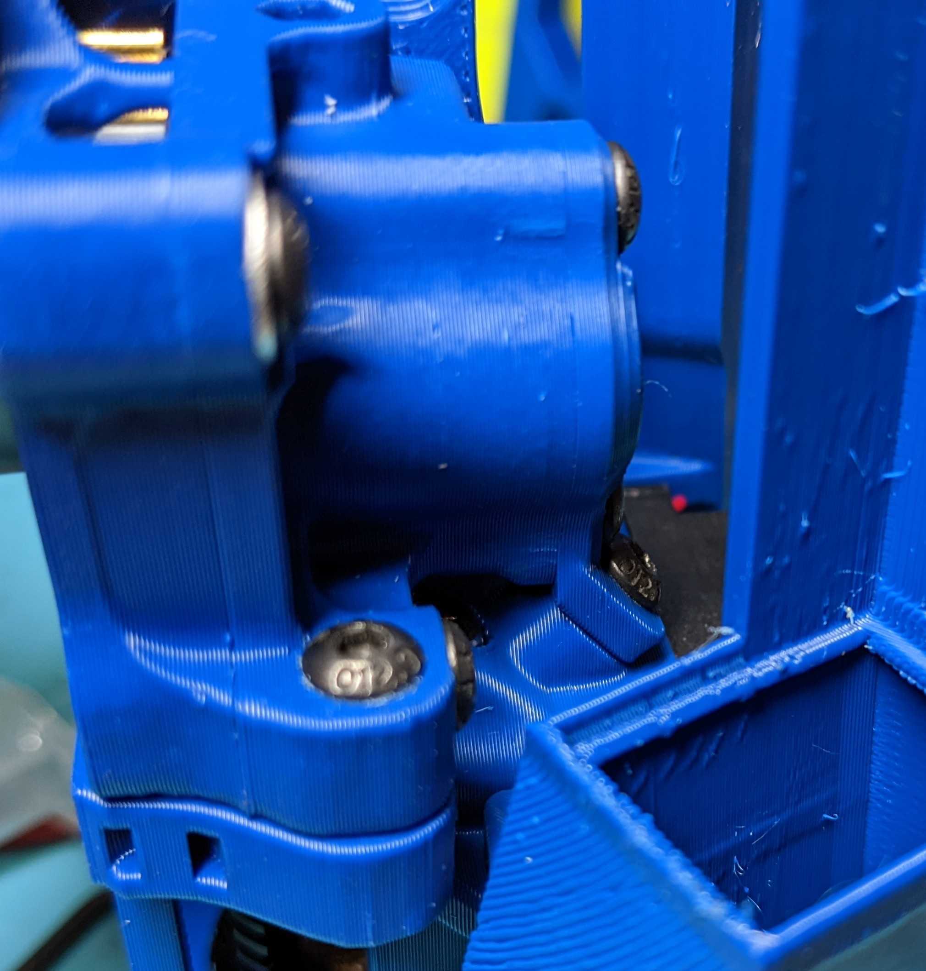
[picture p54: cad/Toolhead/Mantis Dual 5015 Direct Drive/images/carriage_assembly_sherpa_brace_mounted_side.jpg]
    <TD align="CENTER" width=33%><BR></TD>
</table>

- Hotends
  - Dragon and Dragon/Crazy Volcano
    - Both use the same Dragon Hotend Mount
  - Rapido
    - Uses a slightly modified hotend mount that rotates the heatsink slightly.  This is to allow the Rapido sock to be mounted symmetrically at the bottom with the logo forward.  
    - The Rapido sock isn't a symmetrical hexagon.  It is important for the Phaetus logo to be facing forward.  The part cooling ducts for Rapido have been designed to blow air under the sock in this orientation.

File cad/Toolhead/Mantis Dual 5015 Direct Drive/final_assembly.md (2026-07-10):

<table width=100%>
<TR>
<TD align="center"><B>Link</TD><TD align="center"><B>Description</TD></TR>
<TR><TD align="center"><a href="readme.md">Readme</A></TD><TD align="center">Mantis Description and Updates</TD></TR>
<TR><TD align="center"><a href="bom_acknowledgements.md">BOM and Acknowledgements</A></TD><TD align="center">BOM, links to other repositories, acknowledgements</TD></TR>
<TR><TD align="center"><a href="print_orientation.md">Print Orientation</A></TD><TD align="center">Printing the parts</TD></TR>
<TR><TD align="center"><a href="carriage_assembly.md">Carriage Assembly</A></TD><TD align="center">Building the MGN9, MGN12 Carriage, Hotend Mounts</TD></TR>
<TR><TD align="center"><a href="magprobe.md">Magprobe Assembly</A></TD><TD align="center">Assembly of Mag Probe</TD></TR>
<TR><TD align="center"><a href="firmware_slicer_settings.md">Firmware and Slicer Settings</A></TD><TD align="center">Firmware and Slicer Settings</TD></TR>
<TR><TD align="center"><a href="1.8_trident.md">Voron 1.8 and Trident</A></TD><TD align="center">Notes on Voron 1.8 and Trident</TD></TR>
<TR><TD align="center"><a href="final_assembly.md">Final Assembly</A></TD><TD align="center">Notes and Pictures of final assembly</TD></TR>
<TR><TD align="center"><a href="https://github.com/mandryd/MantisUsermods/tree/main/Usermods">Usermods</A></TD><TD align="center">Mods by Mantis Users (note: separate repository)</TD></TR>
<TR><TD align="center"><a href="https://github.com/mandryd/VoronUsers/tree/master/printer_mods/Long/Mantis_Dual_5015">Long's Mantis Repository</A></TD><TD align="center">Long's Repository for Mantis.  Updates and newest stuff will be found here</TD></TR>
</table>

Final Assembly
============
**Final Assembly:**
- Use button heads for everything if possible to save weight
-  ****note the heater cartridge location**
   - heater cartridge should be towards the back
- ADXL can be mounted on the left side of the carriage or using one of the 3010 mount holes.
- Duct_Brace_v1.0.stl can be used to brace the upper duct arms.  
  - The x-axis Resonance grace sometimes has a second resonance at ~110hz.  This brace can help mitigate that.  Prior to the duct brace, I used the MZV recommendation and didn't really have issues with ringing.  The duct brace improves the resonance graph, but I'm not sure if it makes a real world difference in print quality.  
  - Put the duct brace between the two upper duct arm/5015 mount holes and mount the fan to the duct arm and the duct brace with a m3x25.  
<table width=100%>
<TR>
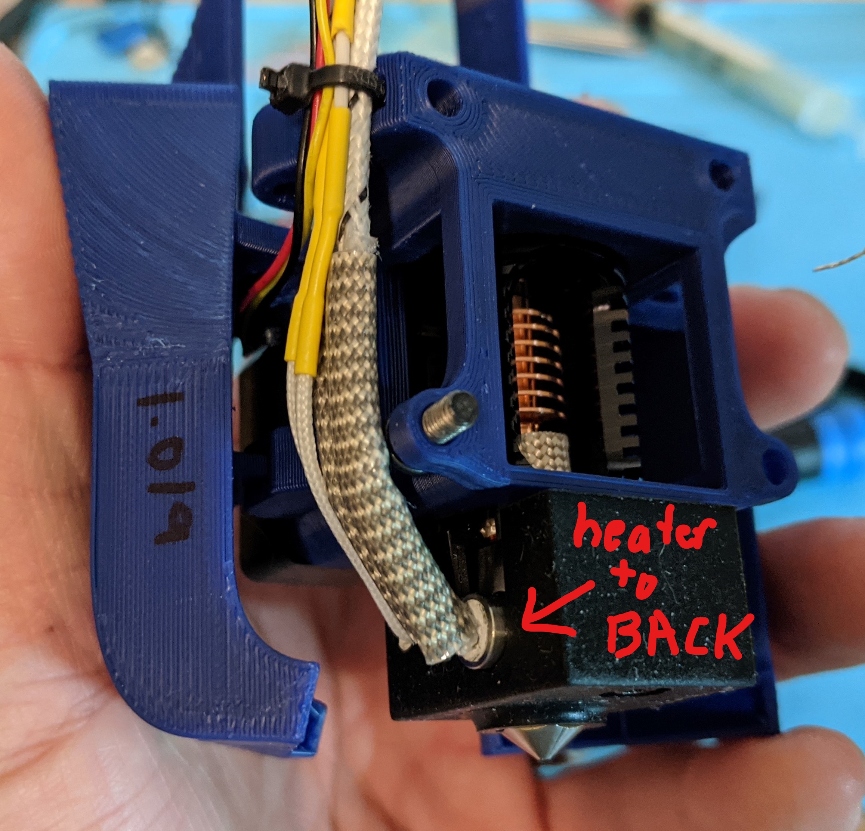
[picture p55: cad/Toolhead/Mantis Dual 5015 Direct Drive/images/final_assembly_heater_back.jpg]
<TD width=50% align="center"><BR>The heater is always oriented towards the back with Mantis</TD>
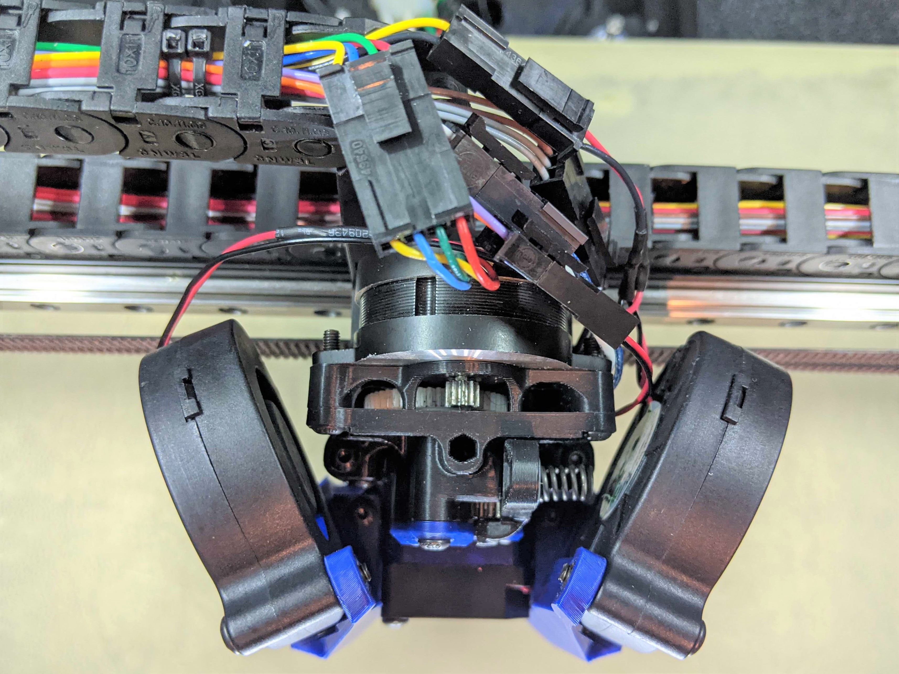
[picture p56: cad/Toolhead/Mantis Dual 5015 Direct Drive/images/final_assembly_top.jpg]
<TD width=50% align="center"><BR>Note you can also use heatsets in the 5015 mount arms</TD>
<TR>
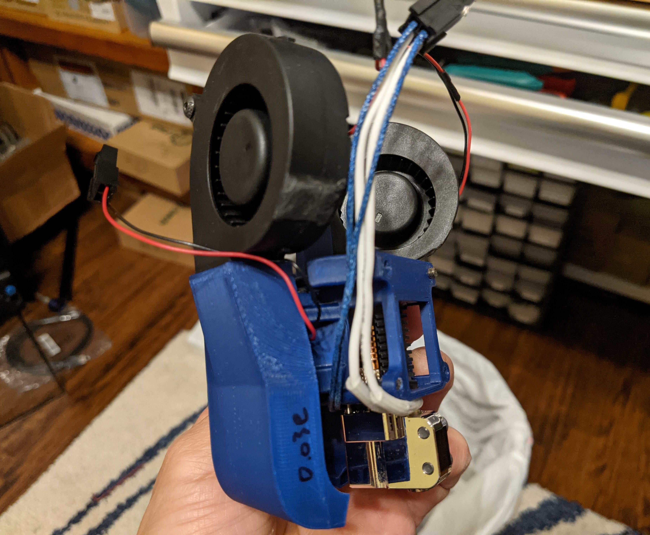
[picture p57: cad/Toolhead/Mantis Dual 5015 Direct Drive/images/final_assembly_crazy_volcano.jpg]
<TD width=50% align="center"><BR>Crazy Volcano.  Heater also goes towards back.</TD>
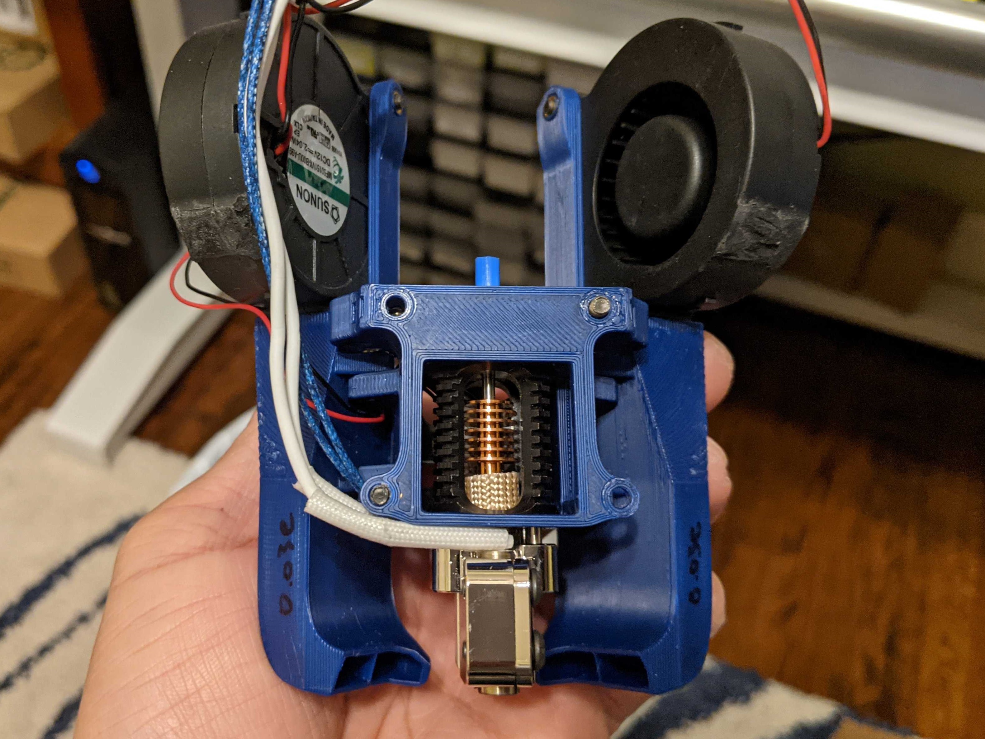
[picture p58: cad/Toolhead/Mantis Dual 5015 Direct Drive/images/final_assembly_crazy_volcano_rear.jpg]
<TD width=50% align="center"><BR>Crazy Volcano's narrow heat block allows nice angles of attack for part cooling to the nozzle and better part cooling airflow than with dragon, mosquito, or rapido.</TD>
</TR>
<TR>
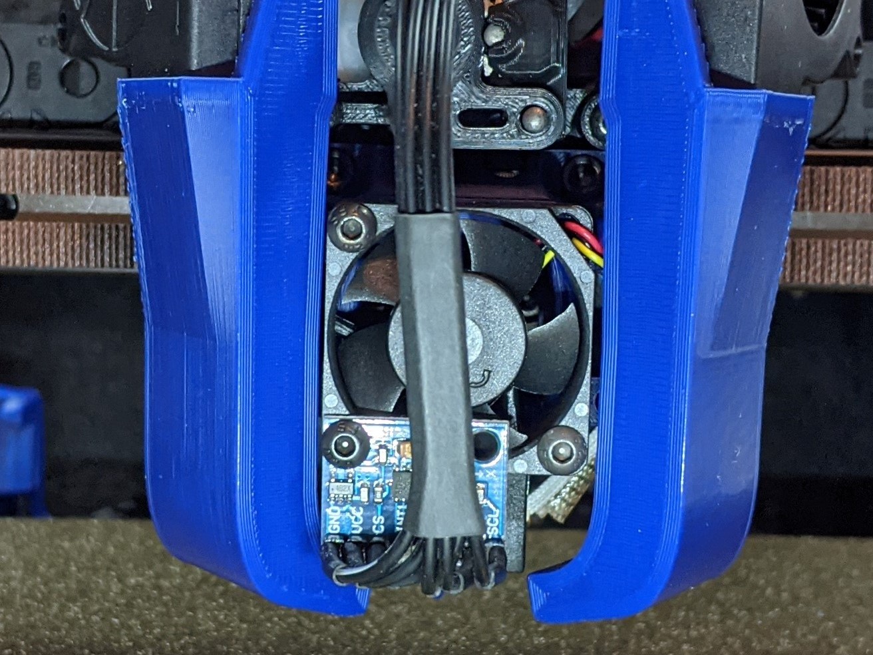
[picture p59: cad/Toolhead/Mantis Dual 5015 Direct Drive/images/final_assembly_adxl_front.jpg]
<TD width=50% align="center"></TD>
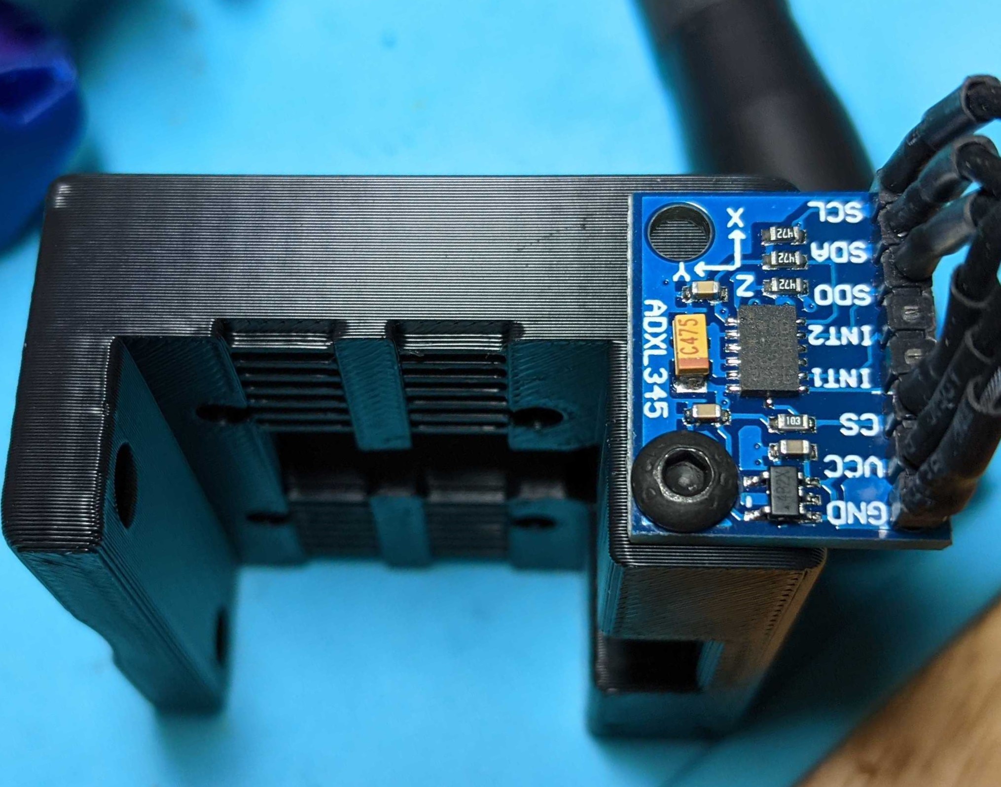
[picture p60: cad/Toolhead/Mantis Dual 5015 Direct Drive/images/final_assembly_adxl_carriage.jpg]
<TD width=50% align="center"></TD>
</TR>
<TR>
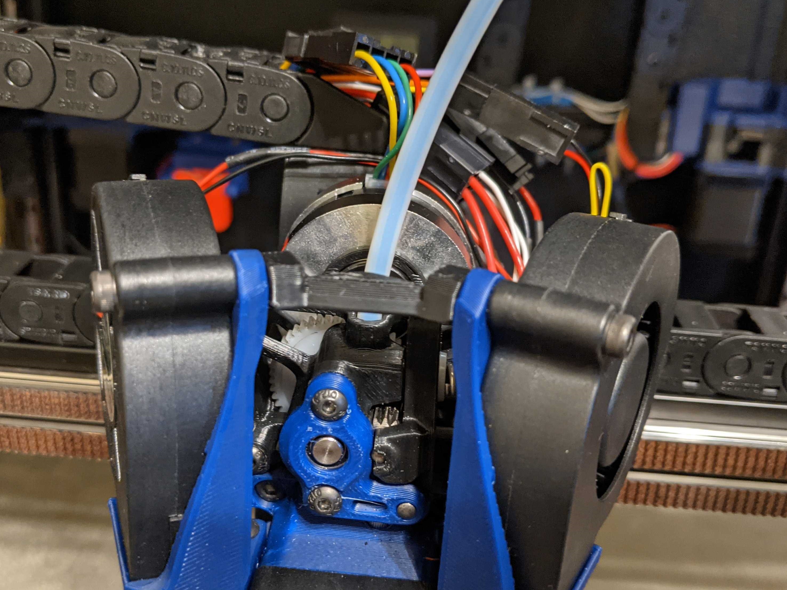
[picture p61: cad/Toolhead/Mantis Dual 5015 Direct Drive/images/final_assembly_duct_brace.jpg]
<TD width=50% align="center"><BR>Duct brace can help with the duct arm stability.</TD>
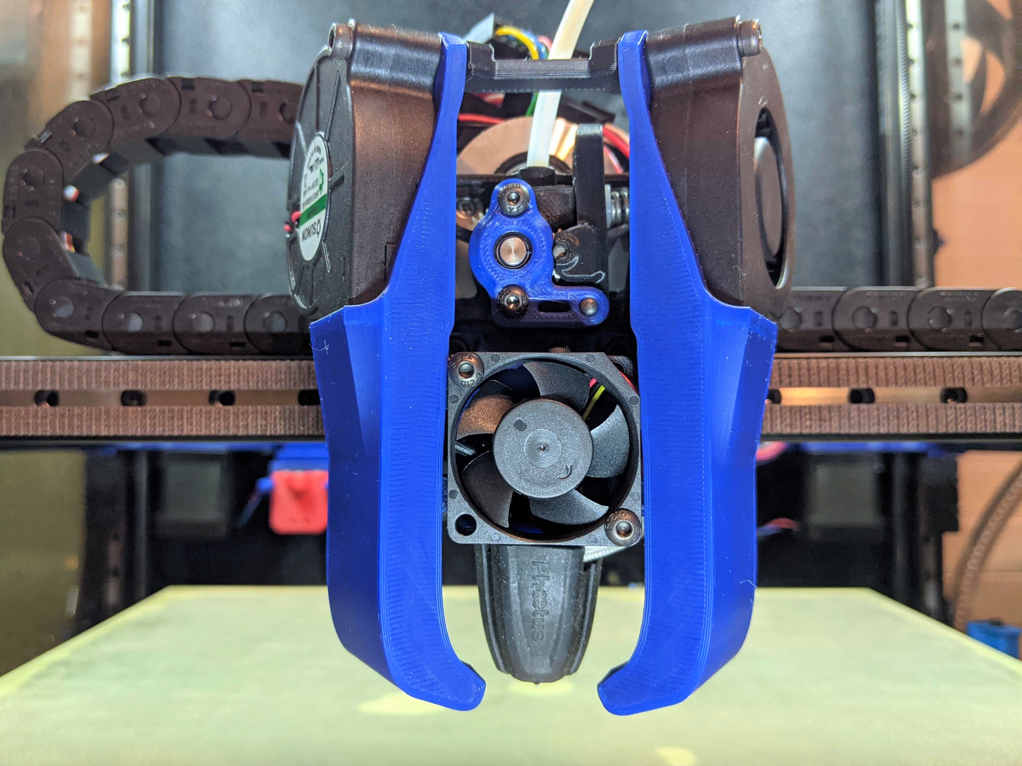
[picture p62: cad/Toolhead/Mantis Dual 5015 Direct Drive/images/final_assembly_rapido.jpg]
<TD width=50% align="center"><BR>Rapido with duct brace.</TD>
</TR>
   
</TABLE>

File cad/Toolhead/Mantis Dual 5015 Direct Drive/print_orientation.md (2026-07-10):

<table width=100%>
<TR>
<TD align="center"><B>Link</TD><TD align="center"><B>Description</TD></TR>
<TR><TD align="center"><a href="readme.md">Readme</A></TD><TD align="center">Mantis Description and Updates</TD></TR>
<TR><TD align="center"><a href="bom_acknowledgements.md">BOM and Acknowledgements</A></TD><TD align="center">BOM, links to other repositories, acknowledgements</TD></TR>
<TR><TD align="center"><a href="print_orientation.md">Print Orientation</A></TD><TD align="center">Printing the parts</TD></TR>
<TR><TD align="center"><a href="carriage_assembly.md">Carriage Assembly</A></TD><TD align="center">Building the MGN9, MGN12 Carriage, Hotend Mounts</TD></TR>
<TR><TD align="center"><a href="magprobe.md">Magprobe Assembly</A></TD><TD align="center">Assembly of Mag Probe</TD></TR>
<TR><TD align="center"><a href="firmware_slicer_settings.md">Firmware and Slicer Settings</A></TD><TD align="center">Firmware and Slicer Settings</TD></TR>
<TR><TD align="center"><a href="1.8_trident.md">Voron 1.8 and Trident</A></TD><TD align="center">Notes on Voron 1.8 and Trident</TD></TR>
<TR><TD align="center"><a href="final_assembly.md">Final Assembly</A></TD><TD align="center">Notes and Pictures of final assembly</TD></TR>
<TR><TD align="center"><a href="https://github.com/mandryd/MantisUsermods/tree/main/Usermods">Usermods</A></TD><TD align="center">Mods by Mantis Users (note: separate repository)</TD></TR>
<TR><TD align="center"><a href="https://github.com/mandryd/VoronUsers/tree/master/printer_mods/Long/Mantis_Dual_5015">Long's Mantis Repository</A></TD><TD align="center">Long's Repository for Mantis.  Updates and newest stuff will be found here</TD></TR>
</table>

Print Orientation
============
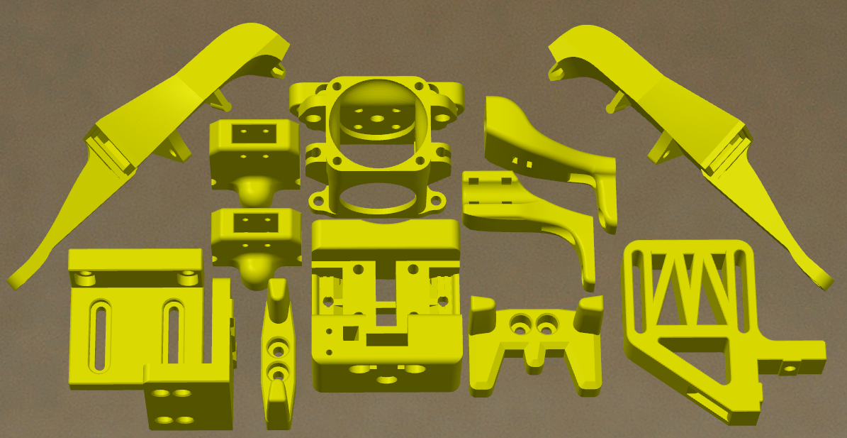
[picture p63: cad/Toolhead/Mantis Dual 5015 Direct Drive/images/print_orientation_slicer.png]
Print Orientation


Slicer Tips:
- Perimeters/Shells
  - 3-4 Perimeters and low infill is adequate.
  - Josh Murrah is using 3perim/40% on his toolhead used in speedruns.
  - I’ve been using 4 perimeters/15%
- Ducts
  - Check that this outlet divider is sliced in a sane way.
  - In superslicer, I find the “keep only bridges” option under "Perimeters & Shell” works well for the ducts
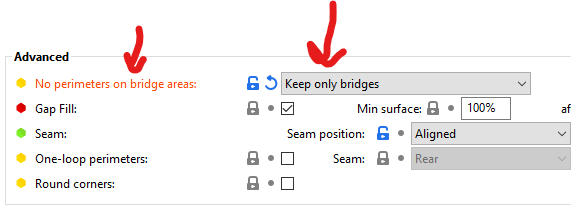
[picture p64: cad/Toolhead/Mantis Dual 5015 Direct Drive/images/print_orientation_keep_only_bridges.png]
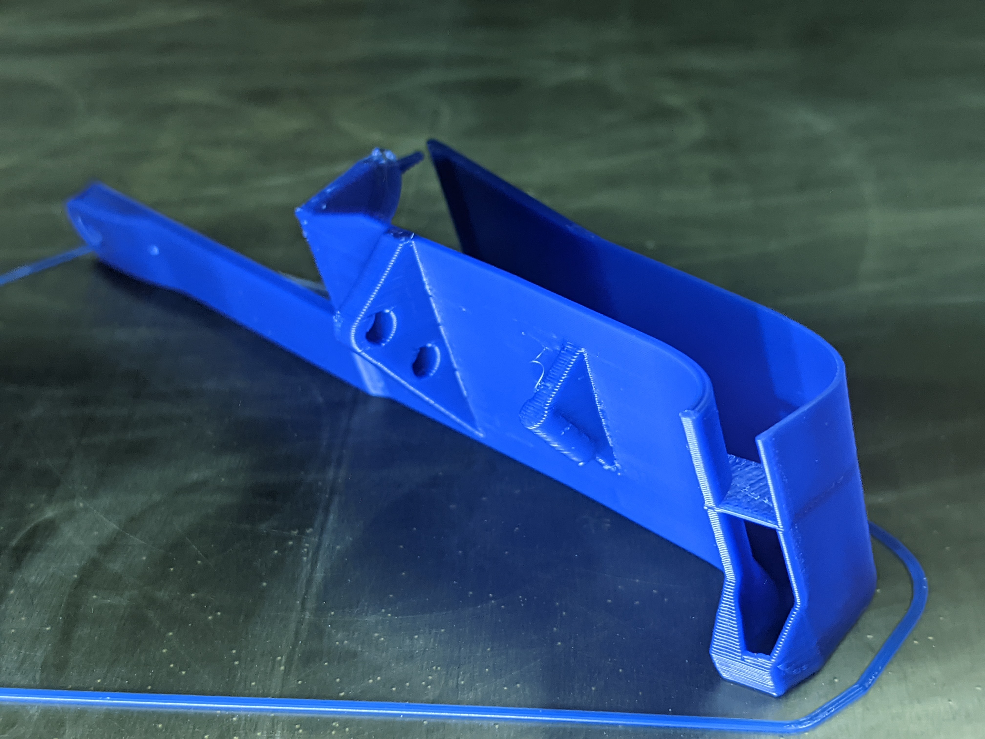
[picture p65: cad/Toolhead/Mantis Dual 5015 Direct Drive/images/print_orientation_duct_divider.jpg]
  - 
  - The ducts have some tough overhangs, so orient the part so the over hangs print the best for you. Prioritize good quality for the outlet. The 5015 mount surface will generally be rough, but that’s ok.
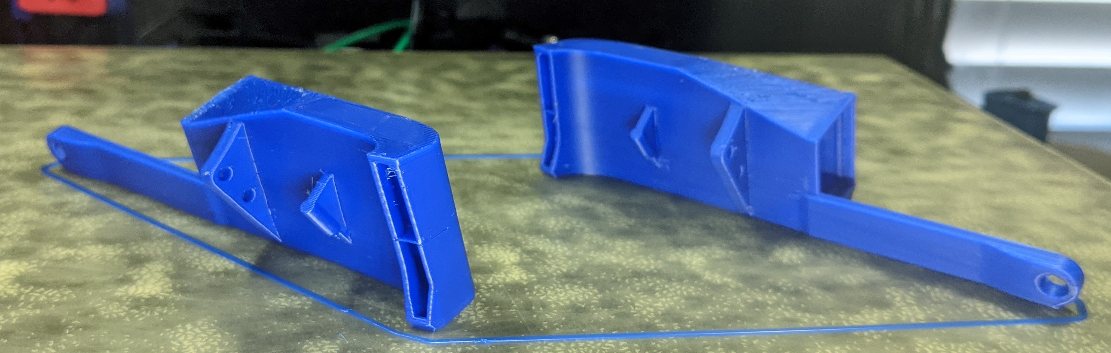
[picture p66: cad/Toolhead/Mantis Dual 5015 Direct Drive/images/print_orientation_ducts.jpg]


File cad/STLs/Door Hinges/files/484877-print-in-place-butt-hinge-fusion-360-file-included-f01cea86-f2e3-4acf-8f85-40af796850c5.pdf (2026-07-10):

# Print In Place Butt Hinge (Fusion 360

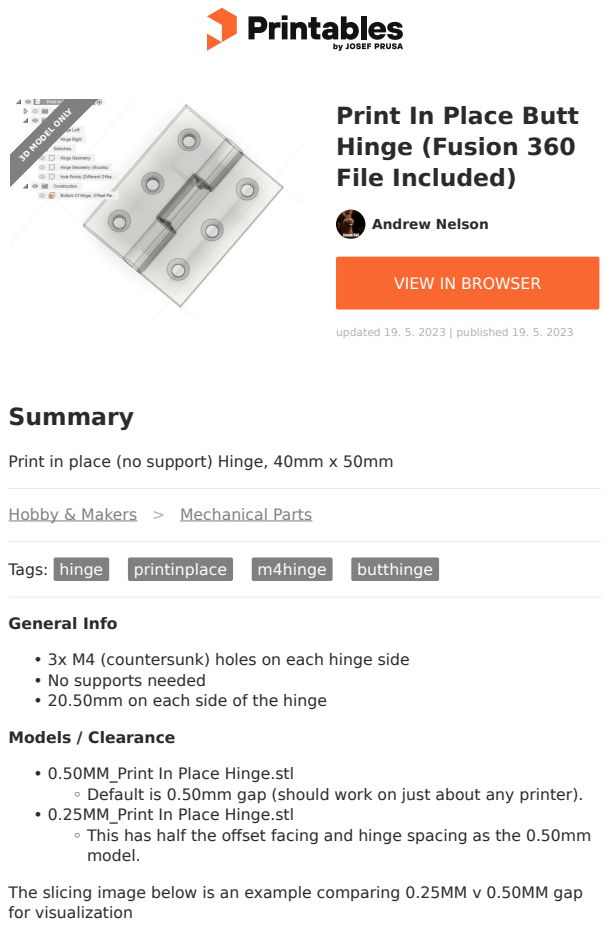
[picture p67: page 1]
Summary; Hobby & Makers; Mechanical Parts; Tags: hinge; printinplace; m4hinge; butthinge; General Info; Models / Clearance; Andrew Nelson; File Included); updated 19. 5. 2023 | published 19. 5. 2023; 3D MODEL ONLY

VIEW IN BROWSER (https://printables.com/model/484877-print-in-place-butt-hinge-fusion-360-file-included)

Print in place (no support) Hinge, 40mm x 50mm

3x M4 (countersunk) holes on each hinge side
No supports needed
20.50mm on each side of the hinge

0.50MM_Print In Place Hinge.stl

Default is 0.50mm gap (should work on just about any printer).
0.25MM_Print In Place Hinge.stl

This has half the offset facing and hinge spacing as the 0.50mm
model.

The slicing image below is an example comparing 0.25MM v 0.50MM gap
for visualization

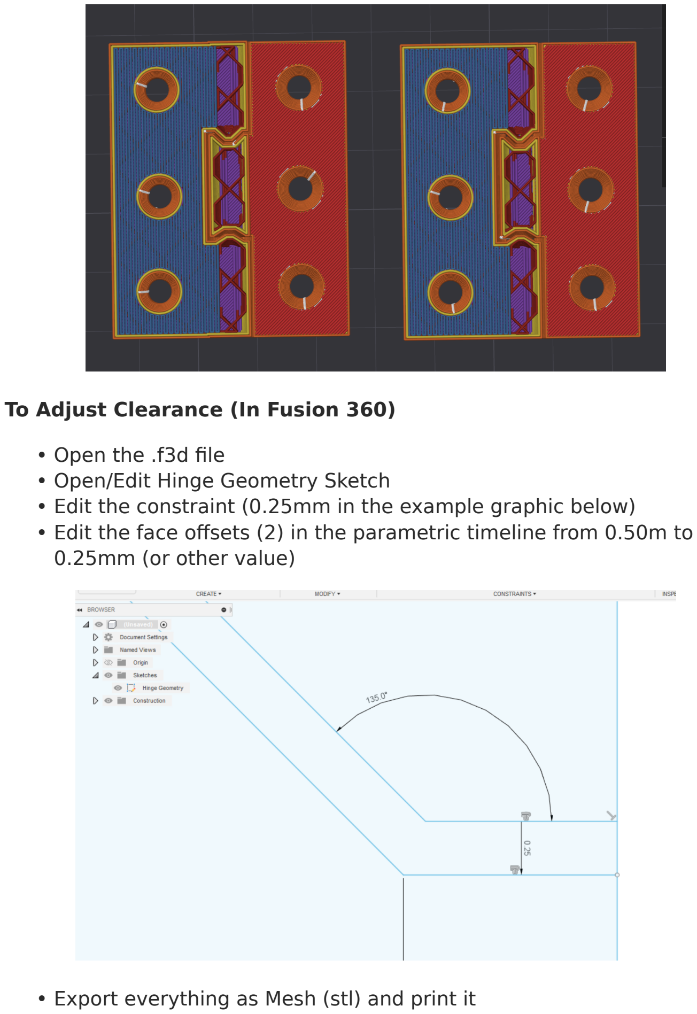
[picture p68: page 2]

### To Adjust Clearance (In Fusion 360)

Open the .f3d file
Open/Edit Hinge Geometry Sketch

Edit the constraint (0.25mm in the example graphic below)

Edit the face offsets (2) in the parametric timeline from 0.50m to

0.25mm (or other value)

Export everything as Mesh (stl) and print it

•
•

•

•

•

# Model files

- Fusion 360 File (to edit sketches, or change the hinge geometry)

# License

This work is licensed under a

Creative Commons (4.0 International License)

Attribution-ShareAlike (http://creativecommons.org/licenses/by-sa/4.0/)

✖ | Sharing without ATTRIBUTION
✔ | Remix Culture allowed
✔ | Commercial Use
✔ | Free Cultural Works
✔ | Meets Open Definition

050mm_print-in-place-hinge.stl

print-in-place-hinge.f3d

025mm_print-in-place-hinge.stl

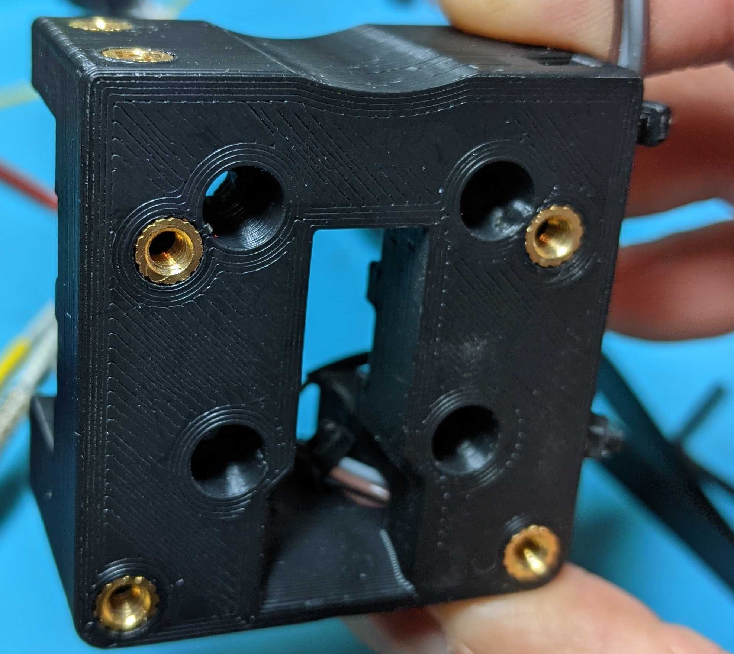
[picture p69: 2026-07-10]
cad/Toolhead/Mantis Dual 5015 Direct Drive/images/carriage_assembly_heatsets.jpg

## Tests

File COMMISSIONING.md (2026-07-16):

# SkipCore350 Commissioning and Print/Test Sequence

Repo target: `SkipHokin/SkipCore350`  
Printer: SkipCore350 CoreXY, BTT Manta M8P v2 + CB1, Klipper  
Coordinate model: rear-right home, `X0 Y0` at rear-right, printable space positive: `X 0..340`, `Y 0..340`
Probe: BLTouch, `X -38`, `Y 2`  
Nozzle: 0.4 mm

> Status: this file is a working commissioning runbook. Tick the boxes as each gate is completed and add notes under each section.

---

## Gate 0 — Safety snapshot

- [X] Backup current `printer.cfg`
- [X] Backup all included `.cfg` files
- [X] Backup Orca profile
- [X] Take photos of wiring and board connections
- [X] Confirm 24 V and mains wiring are mechanically secure
- [X] Confirm bed earth/grounding where applicable

Notes:

```text

```

---

## Gate 1 — Static electrical checks

Do not move motors yet.

- [X] Confirm emergency stop works
- [X] Confirm hotend temperature reads room temperature
- [X] Confirm bed temperature reads room temperature
- [X] Confirm CB1/M8P status is normal
- [X] Confirm no heater is unexpectedly on
- [X] Confirm BLTouch self-test on startup

Useful commands:

```gcode
M112
FIRMWARE_RESTART
STATUS
```

Notes:

```text

```

---

## Gate 2 — Endstops and BLTouch checks

Move the toolhead by hand away from all endstops.

```gcode
QUERY_ENDSTOPS
BLTOUCH_DEBUG COMMAND=pin_down
QUERY_PROBE
BLTOUCH_DEBUG COMMAND=pin_up
QUERY_PROBE
```

Expected:

- [X] X endstop reports open when clear and TRIGGERED when pressed
- [X] Y endstop reports open when clear and TRIGGERED when pressed
- [X] BLTouch reports open when pin down
- [X] BLTouch reports TRIGGERED when pin is gently pushed up

Notes:

```text

```

---

## Gate 3 — Motor direction and tiny moves

Toolhead roughly in the middle by hand. Use small moves only.

```gcode
STEPPER_BUZZ STEPPER=stepper_x
STEPPER_BUZZ STEPPER=stepper_y
STEPPER_BUZZ STEPPER=stepper_z
STEPPER_BUZZ STEPPER=stepper_z1
STEPPER_BUZZ STEPPER=stepper_z2
```

Then:

```gcode
G91
G1 X-10 F1200
G1 X10 F1200
G1 Y-10 F1200
G1 Y10 F1200
G90
```

Expected for this coordinate model:

- [X] `X-10` moves left
- [X] `X10` moves right
- [X] `Y-10` moves toward the front
- [X] `Y10` moves toward the rear
- [X] Z motors all move the same direction
- [X] No binding, grinding, crossed CoreXY motion, or cable-chain issue

Notes:

```text

```

---

## Gate 4 — Homing

Start with XY only.

```gcode
G28 X
G28 Y
G1 X-50 Y-50 F3000
```

For BLTouch centred over the bed, safe Z home nozzle position is approximately:

```ini
[safe_z_home]
home_xy_position: -137, -177
z_hop: 10
z_hop_speed: 5
speed: 80
```

Calculation: probe centre target `X-175 Y-175`; nozzle = probe target minus probe offset = `-175 - (-38)`, `-175 - 2` = `X-137 Y-177`.

Then:

```gcode
G28 Z
```

- [X] X homes to right/rear-right side as expected
- [X] Y homes to rear
- [X] Final XY after homing is `X0 Y0`
- [X] Z homes using BLTouch without nozzle crash

Notes:

```text

```

---

## Gate 5 — Travel limit validation

Do not immediately use the full 350 mm. Walk up to it.

```gcode
G1 Z20 F600
G1 X-50 Y-50 F3000
G1 X-300 Y-50 F3000
G1 X-300 Y-300 F3000
G1 X-50 Y-300 F3000
G1 X-50 Y-50 F3000
```

Then expand carefully:

```gcode
G1 X330 Y330 F3000
```

- [X] Belt paths clear
- [X] Cable chains clear
- [X] BLTouch clears belts and frame
- [X] Toolhead clears frame extremes
- [X] True available X travel recorded
- [X] True available Y travel recorded

Measured travel:

```text
X travel: 340
Y travel: 330
Z travel: 300
```

Notes:

```text

```

---

## Gate 6 — Probe Z offset and repeatability

```gcode
G28
PROBE_CALIBRATE
```

During calibration:

```gcode
TESTZ Z=-0.1
TESTZ Z=0.05
ACCEPT
SAVE_CONFIG
```

Then:

```gcode
G28
PROBE_ACCURACY
```

Targets:

- [ ] Probe range under 0.02 mm: excellent
- [ ] Probe range under 0.05 mm: usable
- [ ] Over 0.05 mm: investigate probe mount, pin, wiring, bed movement

Recorded probe accuracy:

```text
samples: 10
range: 0.008750 mm
standard deviation: 0.002453 mm
average: 0.011875 mm
```

Notes:

```text

```

---

## Gate 7 — Z tilt

```gcode
G28
Z_TILT_ADJUST
G28 Z
Z_TILT_ADJUST
```

- [X] First run completes
- [X] Second run makes only a tiny correction
- [X] Bed is not chasing itself up/down repeatedly

Notes:

```text

```

---

## Gate 8 — Conservative bed mesh

Starting conservative mesh:

```ini
[bed_mesh]
speed: 120
horizontal_move_z: 8
mesh_min: -300, -300
mesh_max: -60, -30
probe_count: 5,5
algorithm: bicubic
```

Run:

```gcode
G28
Z_TILT_ADJUST
G28 Z
BED_MESH_CALIBRATE
SAVE_CONFIG
```

- [ ] Mesh completes without out-of-range moves
- [ ] BLTouch stays over bed for all probe points
- [ ] Mesh looks plausible, not wild or sloped beyond mechanical expectation

Notes:

```text

```

---

## Gate 9 — Hotend and bed temperature stability

Temperature challenge history to document:

- Earlier fault: `Extruder not heating at expected rate` around 40–42 °C
- 24 V was measured
- Heater cartridge and/or thermistor were replaced/checked
- Later heating appeared OK
- Fan mapping and heatbreak fan behaviour need to be confirmed before long prints

Checks:

```gcode
PID_CALIBRATE HEATER=extruder TARGET=220
SAVE_CONFIG
PID_CALIBRATE HEATER=heater_bed TARGET=60
SAVE_CONFIG
```

- [X] Hotend heats from room temp to 220 °C normally
- [X] No heater rate fault
- [X] Hotend holds stable after PID tune
- [X] Bed heats to 60 °C normally
- [X] Bed holds stable after PID tune
- [X] Heatbreak fan comes on at correct temperature
- [X] Part fans stay off unless requested

Notes:

```text
Hotend PID at 220 °C
Kp: 44.368
Ki: 5.378
Kd: 91.509

Bed PID at 60 °C
Kp: 63.508
Ki: 1.687
Kd: 597.765
```

---

## Gate 10 — Extruder rotation distance

Heat to printing temperature:

```gcode
M109 S220
```

Mark filament 120 mm above extruder entry, then:

```gcode
G91
G1 E100 F60
G90
```

Formula:

```text
new_rotation_distance = old_rotation_distance × actual_extruded / requested_extruded
```

- [X] 100 mm command gives 99–101 mm actual
- [X] No skipping
- [X] No grinding filament
- [X] Hotend flow seems normal

Recorded result:

```text
old rotation_distance: 118
requested extrusion: 100
actual extrusion: 100
new rotation_distance: 100
```

Notes:

```text

```

---

# Print and STL commissioning sequence

This section is the suggested print/tune order after the mechanical/electrical gates above.

## Print 1 — First-layer square / squaring plane

Purpose: confirm Z offset, mesh, extrusion, and bed adhesion before wasting time on cubes.

Suggested model:

- Single-layer square, 100 x 100 mm initially
- Then 250 x 250 mm or larger once safe
- 0.20 mm first layer
- PLA first if available

Settings:

```text
Layer height: 0.20 mm
First layer: 0.20 mm
Speed: slow, 20–30 mm/s first layer
Bed: PLA 55–60 °C
Nozzle: PLA 200–215 °C
Fan: off for first layer, normal after
```

Pass:

- [X] Lines touch neatly
- [X] No ploughing
- [X] No round loose strings
- [X] Same first-layer quality across the tested area

Notes:

```text

```

---

## Print 2 — Calibration cube

Purpose: basic dimensional sanity, extrusion consistency, and axis behaviour.

Suggested model:

- 20 mm XYZ cube
- 2–3 walls
- 15–20% infill
- 0.20 mm layers

Pass:

- [ ] No layer shift
- [ ] X and Y dimensions plausible
- [ ] Z height plausible
- [ ] Corners not wildly bulged
- [ ] Top surface acceptable

Measurements:

```text
X:
Y:
Z:
Notes:
```

---

## Print 3 — Larger squareness / gantry check plane

Purpose: check skew, square, belt tension, and motion over a larger area.

Suggested models:

- 200 x 200 mm square outline
- 250 x 250 mm diagonal cross
- Thin rectangular frame

Check:

- [ ] Diagonals match
- [ ] Corners are square
- [ ] No obvious CoreXY racking
- [ ] No belt tooth artefacts or missed steps

Measurements:

```text
Front-left to rear-right diagonal:
Front-right to rear-left diagonal:
Difference:
```

---

## Print 4 — Flow test

Purpose: tune extrusion multiplier/flow before pressure advance.

Suggested approach:

- Orca Slicer flow calibration
- Or single-wall cube if preferred

Pass:

- [ ] Wall thickness sensible
- [ ] Top infill not overstuffed
- [ ] No under-extruded gaps

Recorded flow:

```text
Material:
Temperature:
Flow / extrusion multiplier:
```

---

## Print 5 — Pressure Advance tower

Purpose: tune corners and acceleration pressure response.

Prerequisites:

- Flow roughly correct
- Extruder rotation distance correct
- Hotend temperature stable
- No major mechanical problems

Suggested:

- Orca pressure advance test
- Start conservative; do not chase speed yet

Pass:

- [ ] Corners sharpen without under-extruding
- [ ] No severe gaps after corners
- [ ] Value recorded in Klipper or slicer profile

Recorded PA:

```text
Material:
Nozzle:
Temperature:
Speed:
PA value:
```

---

## Print 6 — Temperature tower

Purpose: find useful temperature range for the actual hotend/material combo.

Suggested:

- PLA tower first
- Then PETG/ABS/ASA later

Check:

- [ ] Layer bonding
- [ ] Stringing
- [ ] Bridging
- [ ] Overhangs
- [ ] Surface finish

Recorded result:

```text
Material:
Brand:
Best temperature:
Acceptable range:
Notes:
```

---

## Print 7 — Speed / heat / volumetric flow test

Purpose: find practical flow limit of hotend/extruder before input shaping heroics.

Suggested:

- Orca max volumetric speed test
- Or stepped speed tower

Pass:

- [ ] No extruder skipping
- [ ] No sudden matte/under-extruded sections
- [ ] No heat creep
- [ ] No layer shifts

Recorded result:

```text
Material:
Nozzle:
Layer height:
Line width:
Max reliable volumetric flow:
Max useful print speed:
```

---

## Print 8 — Input shaper / accelerometer workflow

Hardware note:

- Accelerometer to be mounted rigidly to the toolhead.
- Process may be run through BTT Pad 7 if that is where the accelerometer tooling is available.
- Results can later be transferred into the CB1 Klipper config.

Before test:

- [ ] Find accelerometer
- [ ] Mount firmly to toolhead/head plate
- [ ] Confirm orientation
- [ ] Confirm wiring/USB/SPI method
- [ ] Confirm Pad 7 can communicate with accelerometer

Run resonance tests when ready:

```gcode
SHAPER_CALIBRATE AXIS=X
SHAPER_CALIBRATE AXIS=Y
SAVE_CONFIG
```

Record:

```text
X recommended shaper:
X frequency:
Y recommended shaper:
Y frequency:
Acceleration limit recommendation:
Where results were generated: BTT Pad 7 / CB1 / other
Date:
```

Pass:

- [ ] Graphs/results captured
- [ ] Values transferred to CB1 config if generated elsewhere
- [ ] Test cube after shaping shows reduced ringing

---

## Print 9 — Real-world validation prints

Only after gates and tuning prints:

- [ ] Functional bracket
- [ ] Longer print, 2–3 hours
- [ ] Larger bed-area print
- [ ] Higher-temperature material test if enclosure is ready
- [ ] Repeatable start/end macro behaviour

Notes:

```text

```

---

# Known configuration anchors

## Fan mapping candidate

```text
FAN0 PF7 → part cooling 24 V
FAN1 PF9 → heatbreak temp-controlled 24 V
FAN2 PF6 → 12 V case always-on
FAN3 PF8 → 24 V case always-on
```

## Known/current printer facts

```text
Printer: SkipCore350
Controller: BTT Manta M8P v2 + CB1
Drivers: TMC2209
Motion: CoreXY, 9 mm GT2 belts
Bed: 350 x 350 x 8 mm aluminium, 230 VAC 500 W silicone heater
Hotend: E3D Revo Ceramic currently noted; Rapido 2 UHF considered
Extruder: HGX Lite 2.0 / Moons NEMA14, gear ratio 19:2, rotation_distance around 7.5 earlier
Probe: BLTouch, X -38, Y 2
Coordinate model: rear-right home, negative printable X/Y space
```

---

# Running log

| Date | Gate/Test | Result | Notes |
|---|---|---|---|
| | | | |

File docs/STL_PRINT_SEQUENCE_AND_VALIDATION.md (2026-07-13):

# SkipCore350 STL Print Sequence and Validation

This document defines the practical print-test sequence for commissioning SkipCore350.

The aim is not to print a Benchy first. The aim is to validate one system at a time: first layer, XY squareness, extrusion, pressure advance, temperature stability, flow limit, then input shaping.

---

## Test order summary

1. First-layer square / squaring plane.
2. Calibration cube.
3. Larger squareness plane.
4. Flow calibration.
5. Pressure Advance tower.
6. Temperature tower.
7. Speed / heat / volumetric flow test.
8. Accelerometer / input shaper testing.
9. Functional printer part.
10. Cosmetic benchmark print.

---

## General starting profile

Use conservative slicer settings until the machine proves itself.

```text
Nozzle: 0.4 mm
Layer height: 0.20 mm
Material: PLA or PLA+
Bed: 60 °C typical starting point
Hotend: 200–220 °C depending on filament
Speed: 40–50 mm/s for first tests
Acceleration: conservative
Part fan: limited, especially with Revo Ceramic and dual 5010 fans
Pressure Advance: off or baseline until PA test
Input Shaper: off or conservative until accelerometer test
```

---

## 1. First-layer square / squaring plane

Purpose:

- Validate Z offset.
- Validate bed mesh compensation.
- Validate extrusion starts cleanly.
- Check if nozzle is too high/low.
- Check if the machine can lay down a simple continuous first layer.

Suggested part:

```text
Single-layer square, 100 x 100 mm or 150 x 150 mm
0.20 mm layer height
2–4 perimeter outline optional
```

Record:

```text
Date:
Material:
Nozzle temp:
Bed temp:
Z offset:
Bed mesh active: yes/no
Result:
Comments:
```

Pass condition:

- Lines touch without ploughing.
- No gaps between adjacent lines.
- Corners remain stuck.
- No obvious mesh compensation error.

---

## 2. Calibration cube

Purpose:

- Confirm basic extrusion and motion.
- Check X/Y/Z dimensions.
- Check layer consistency.
- Check ringing before fast tuning.

Suggested part:

```text
20 mm cube
0.20 mm layers
2–3 walls
15–20% infill
moderate speed
```

Measurements:

| Axis | Target | Measured | Error | Notes |
|---|---:|---:|---:|---|
| X | 20.00 mm | | | |
| Y | 20.00 mm | | | |
| Z | 20.00 mm | | | |

Pass condition:

- No layer shift.
- No obvious under-extrusion.
- Dimensions are close enough for early commissioning.
- Corners give clues for PA, but do not tune everything from the first cube.

---

## 3. Larger squareness / diagonal plane

Purpose:

- Check XY squareness over a bigger area.
- Check if CoreXY belt path or frame alignment is skewed.
- Check useful bed area before large prints.

Suggested part:

```text
Large thin square or rectangle, e.g. 200 x 200 mm or 250 x 250 mm
1–2 layers
Add diagonal or corner markers if useful
```

Measurements:

```text
Front-left to rear-right diagonal:
Front-right to rear-left diagonal:
Difference:
Notes:
```

Pass condition:

- Diagonals are close.
- Corners remain adhered.
- No obvious bed mesh edge problems.

---

## 4. Flow calibration

Purpose:

- Set slicer flow/extrusion multiplier after extruder rotation distance is already correct.

Do not use flow compensation to hide incorrect extruder rotation distance.

Record:

```text
Date:
Material:
Extruder rotation distance:
Slicer flow before:
Slicer flow after:
Test method:
Result:
```

---

## 5. Pressure Advance tower

Purpose:

- Tune corner quality and pressure response.
- Reduce bulging and corner blobbing.

Suggested order:

1. Confirm extruder rotation distance.
2. Confirm reasonable first layer.
3. Confirm flow.
4. Run PA tower.

Record:

```text
Date:
Material:
Nozzle:
Layer height:
Speed:
PA test range:
Best PA value:
Config updated: yes/no
Notes:
```

Known reference from earlier machines:

```text
Ender 5 Pro pressure advance reference was around 0.122.
SkipCore early tests may land elsewhere depending on extruder, Bowden/direct path, hotend, and filament.
```

Pass condition:

- Corners sharper without under-extruded gaps.
- PA value is recorded in config or slicer notes.

---

## 6. Temperature tower

Purpose:

- Find the best print temperature for a specific filament and hotend.
- Check bridging, surface, layer adhesion, stringing, and hotend stability.

Record:

| Material | Brand | Colour | Temp range | Best temp | Notes |
|---|---|---|---|---:|---|
| | | | | | |

Pass condition:

- Hotend holds temperature during fan changes.
- Chosen temperature balances strength and print quality.

---

## 7. Speed / heat / volumetric flow test

Purpose:

- Find the useful speed limit for the current hotend/extruder/material combination.
- Separate motion limits from hotend melt-flow limits.

Watch for:

- Under-extrusion at high speed.
- Extruder clicking/skipping.
- Weak layer bonding.
- Temperature drop during fast sections.
- Heat creep.
- Fan-induced hotend faults.

Record:

```text
Date:
Hotend:
Extruder:
Material:
Nozzle:
Layer height:
Line width:
Max reliable volumetric flow:
Max practical print speed:
Failure mode:
Notes:
```

---

## 8. Accelerometer / input shaper

Purpose:

- Measure X/Y resonances.
- Select input shaper and safe acceleration.

Current plan:

- Find accelerometer.
- Mount it rigidly to the head/toolhead.
- BTT Pad 7 can be used for the test process if it is easier.
- Transfer the final shaper values to the CB1 Klipper config.

Record:

```text
Date:
Accelerometer:
Mounted where:
Test host: BTT Pad 7 / CB1 / other
X recommended shaper:
X frequency:
Y recommended shaper:
Y frequency:
Recommended max acceleration:
Values copied to CB1 config: yes/no
Notes:
```

Pass condition:

- Accelerometer mounted solidly.
- Resonance graphs generated successfully.
- Config values recorded and committed.
- Print confirms ringing improvement.

---

## 9. Functional printer part

Purpose:

- Validate that the printer can produce useful parts, not just tuning artifacts.

Suggested first functional parts:

- Small bracket.
- Cable clip.
- Fan duct revision.
- Webcam cradle piece.
- Belt clamp spare.

Record:

```text
Part:
STL path:
Material:
Print settings:
Fit result:
Changes needed:
```

---

## 10. Cosmetic benchmark print

Only after the boring engineering tests pass.

Candidate:

- Benchy.
- Overhang/bridge test.
- Orca calibration model.

Record:

```text
Model:
Material:
Speed:
Acceleration:
PA:
Input shaper:
Cooling:
Result:
Photos:
```

---

## Print validation log

| Date | Test | Material | Key settings | Result | Next action |
|---|---|---|---|---|---|
| | First-layer square | | | | |
| | Cube | | | | |
| | PA tower | | | | |
| | Temp tower | | | | |
| | Speed test | | | | |
| | Input shaper | | | | |

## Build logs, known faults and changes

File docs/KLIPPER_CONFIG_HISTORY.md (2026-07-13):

# SkipCore350 Klipper Config History

This document records important Klipper configuration decisions and changes.

The actual config files remain the source of truth. This file explains why values were chosen, what was tested, and what should not be changed casually.

---

## Machine identity

```text
Printer: SkipCore350
Controller: BTT Manta M8P v2.0
Host: onboard CB1
Firmware: Klipper
Kinematics: CoreXY
Home position: rear-right
Coordinate system: rear-right is X0 Y0
Printable space: negative X and negative Y from home
Bed size: 350 x 350 mm
Nozzle: 0.4 mm during early commissioning
```

---

## Coordinate convention

Rear-right is home and is treated as X0 Y0.

```text
Rear-left          Rear-right / home
X-350 Y0          X0 Y0

Front-left        Front-right
X-350 Y-350       X0 Y-350
```

Centre nozzle position:

```text
X-175 Y-175
```

---

## Probe / BLTouch

Current known BLTouch offset:

```ini
x_offset: -38
y_offset: 2
```

This means the probe is 38 mm left of the nozzle and 2 mm behind/positive-Y of the nozzle under the current coordinate convention.

Probe-centred safe-home nozzle position for bed centre:

```text
Probe target: X-175 Y-175
Nozzle X = -175 - (-38) = -137
Nozzle Y = -175 - 2 = -177
Suggested safe_z_home: X-137 Y-177
```

Candidate config:

```ini
[safe_z_home]
home_xy_position: -137, -177
z_hop: 10
z_hop_speed: 5
speed: 80
```

Validation:

- [ ] Confirm BLTouch triggers correctly using `QUERY_PROBE`.
- [ ] Confirm safe Z home places probe over bed centre.
- [ ] Confirm no nozzle/bed collision.
- [ ] Confirm probe repeatability using `PROBE_ACCURACY`.

---

## Endstops

Known convention:

```text
X homes to the right.
Y homes to the rear.
Home is rear-right.
```

Validation:

```gcode
QUERY_ENDSTOPS
```

Expected when not triggered:

```text
x: open
y: open
z/probe: open
```

Record:

```text
Date:
X endstop state:
Y endstop state:
Probe state:
Fixes needed:
```

---

## Motor direction and CoreXY validation

Small relative move test after stepper buzz:

```gcode
G91
G1 X-10 F1200
G1 X10 F1200
G1 Y-10 F1200
G1 Y10 F1200
G90
```

Expected:

```text
X-10 = left
X10  = right
Y-10 = front
Y10  = rear
```

Record:

```text
Date:
X move correct: yes/no
Y move correct: yes/no
CoreXY crossed behaviour: yes/no
Fix:
```

---

## Z system

Known design notes:

- Triple Z leadscrew system.
- Z-tilt is part of commissioning.
- Z bracket orientation was improved by flipping the bracket, gaining about 40 mm additional Z travel.

Record final Z configuration:

```text
Lead screw type:
Stepper count:
Driver current:
Microsteps:
Rotation distance:
Z max travel:
Z tilt points:
```

---

## Bed mesh

Because the probe has an X offset of -38, the reachable probe area is smaller than the nozzle travel area.

Conservative starting mesh:

```ini
[bed_mesh]
speed: 120
horizontal_move_z: 8
mesh_min: -300, -300
mesh_max: -60, -30
probe_count: 5,5
algorithm: bicubic
```

Expand only after proving motion limits and probe reach.

Mesh record:

```text
Date:
mesh_min:
mesh_max:
probe_count:
algorithm:
mesh result:
edge issues:
```

---

## Extruder

Known notes:

- HGX Lite 2.0 style extruder.
- Gear ratio reference: 19:2 / 9.5:1.
- Earlier corrected extrusion reference indicated rotation distance around 7.5, but this must be confirmed on the actual current build.

Calibration formula:

```text
new_rotation_distance = old_rotation_distance x actual_extruded / requested_extruded
```

Record:

```text
Date:
Old rotation distance:
Requested extrusion:
Actual extrusion:
New rotation distance:
Saved: yes/no
```

---

## Fans

Known notes:

- FAN0 likely hotend fan.
- FAN1 likely part cooling fan.
- Dual 5010 part cooling should be limited during Revo Ceramic testing.

Final mapping:

```text
FAN0:
FAN1:
FAN2:
Other:
```

Validation:

```text
Date:
Command used:
Observed fan:
Correct mapping: yes/no
```

---

## Temperature config

Record final confirmed sensor and heater settings:

```text
Hotend sensor type:
Hotend pin:
Hotend PID:
Bed sensor type:
Bed pin:
Bed heater pin/SSR:
Bed PID:
Max temp limits:
Thermal safety notes:
```

---

## Pressure Advance

Record tuned values by material and toolhead state:

| Date | Material | Extruder path | Hotend | PA value | Notes |
|---|---|---|---|---:|---|
| | | | | | |

---

## Input Shaper

Record final values after accelerometer testing:

```text
Date:
Accelerometer:
Test host: BTT Pad 7 / CB1 / other
X shaper:
X frequency:
Y shaper:
Y frequency:
Max acceleration recommendation:
Config updated: yes/no
```

---

## Commit log for config changes

Use this table when committing config changes.

| Date | Commit | Config area | Reason | Result |
|---|---|---|---|---|
| | | | | |

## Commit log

2025-06-29 Add initial imported STLs from SimpleCore for bed gantry and X-carriage mounts - Includes linear rail mounts and GT2 belt tensioners - Attribution and license info pending review
    [1 X A_Motor_Mount_MK1.stl, 1 X B_Motor_Mount_MK1.stl, Rear_PSU_Mount.stl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]
2025-07-14 Updated files. Work in progress. Frame is progressing
    [LeadScrew 8mm x 2mmPitch.SLDPRT, LeadScrew Nut 8mm x 2mmPitch.SLDPRT, Power_Inlet_Mount.stl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]
2026-07-10 cad: update SkipCore printed parts and Blender sources
    [0.25MM_Print In Place Hinge.stl, 0.50MM_Print In Place Hinge.stl, BL Touch Mount 2.stl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]
2026-07-10 hardware: update BOM and supporting design files
    [BlTouch Rough.stp, Drag Chain Link 10x15.stp, GT2 Belt 6mm Section.stp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]
2026-07-13 docs: add commissioning and print tuning sequence
2026-07-13 docs: add temperature challenge history
2026-07-13 docs: add STL print sequence and validation log
2026-07-13 docs: add BOM and purchase notes
2026-07-13 docs: add Klipper config history template
2026-07-13 test_prints: add first-layer squaring print notes
2026-07-13 test_prints: add 100x100 one-layer square STL
    [SkipCore350_100x100_1layer_square.stl]
2026-07-14 test_prints: add slow commissioning Orca project
    [SkipCore350_100x100_1layer_square_SLOW_COMMISSIONING.3mf]
2026-07-14 test_prints: add 3-4-5 triangle squareness gauge STL
    [SkipCore350_160x120x200_triangle_squareness_gauge.stl]
2026-07-16 docs: add 20mm calibration cube test
    [SkipCore350_20mm_calibration_cube.stl]
